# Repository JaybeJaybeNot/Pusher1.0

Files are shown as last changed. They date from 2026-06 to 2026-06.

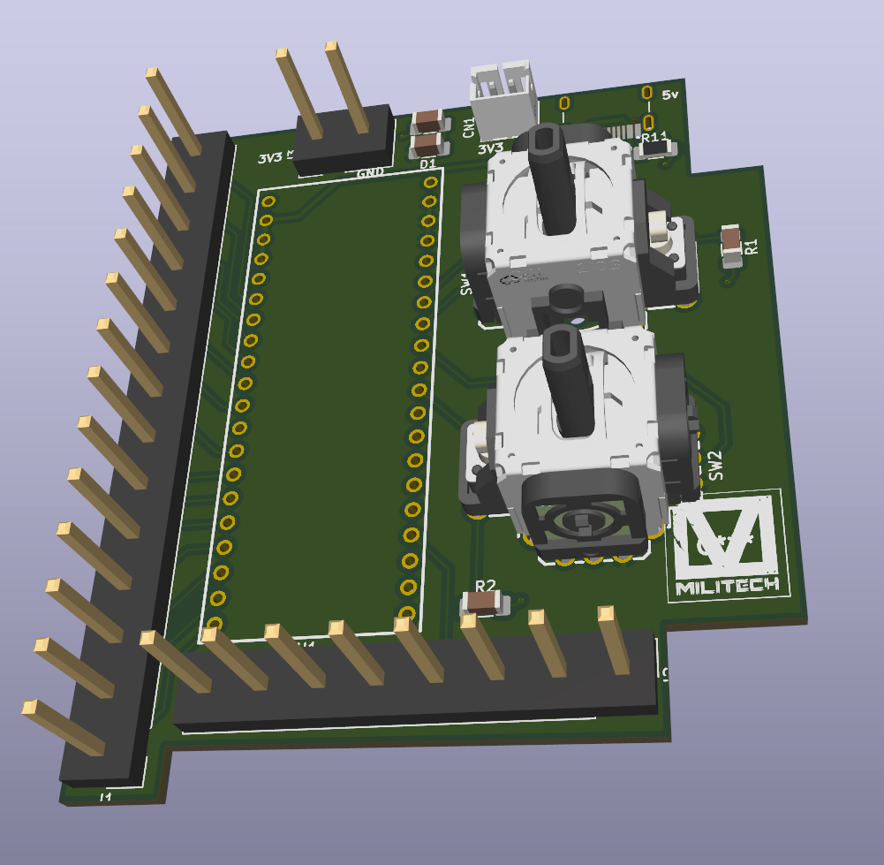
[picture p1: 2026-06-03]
Electrical Design/Joystick_Controller_Preview.png

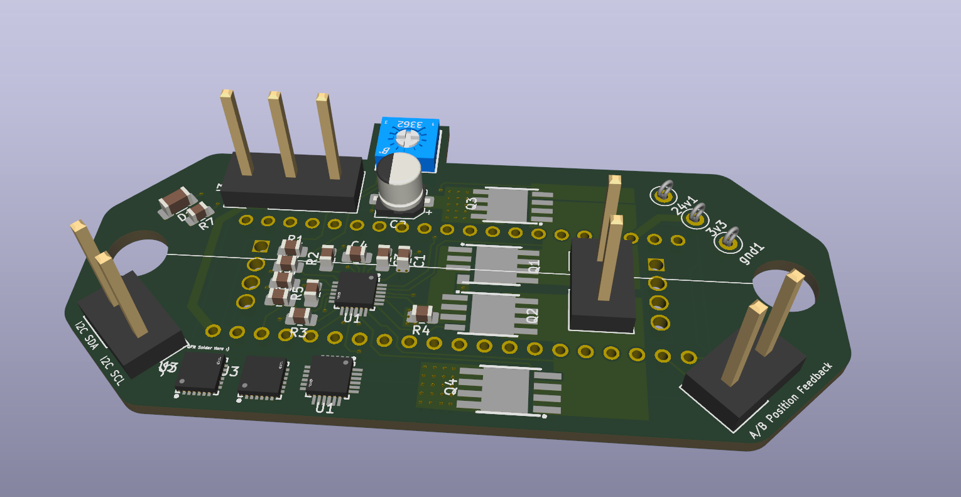
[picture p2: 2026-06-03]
Electrical Design/Motor_Driver_Preview.png

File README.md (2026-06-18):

<p align="center"><i>June 8, 2026</i></p>

Pusher-A5-2

**Affiliation:** Fallout, Hackclub

Sanity Checked by a friend, a CS Graduate from UofM working in robotics.

Pusher is a **4 Degree of Freedom wearable robotic arm** based on the anatomical structure of the human arm, with a maximum reach of approximately **0.65 meters** and a weight of **5 kilograms**. It is designed for **modularity**, aiming to serve as an affordable, general-purpose **research platform** for Human-Computer Interfacing, such as studies involving **EMG, EEG, and Computer Vision**, to assist in the **control of supernumerary arms**. As such, this project is intended for both undergraduate researchers and hobbyists looking for an introduction to the study of HCI robotics, with potential to be used in graduate-school prototyping due to the ease of production and low cost.

***Why I Started This Project***

On the surface level, the this project may seem to simply be a project aiming to develop a supernumerary, robotic arm to assist in human tasks. However, due to the modularity and inexpensiveness of the project, it serves as an amazing platform to prototype with robot theory, from inverse kinematics to computer vision, EEG/EMG signal processing, path planning, control algorithms, etc. without burning cash on hardware. In short, due to my background as an underfunded hardware researcher, I've made the "project to enable future projects"

<h1 align="center"><u>Table of Contents</u></h1>

1. [Bill of Materials](#bill-of-materials)
2. [System Diagram](#system-diagram)
3. [Building the Project](#building-the-project)
   1. [Prerequisites](#prerequisites)
   2. [Assembling Mechanical Design](#assembling-mechanical-design)
   3. [Assembling Electrical Design](#assembling-electrical-design)
   4. [Flashing Firmware](#flashing-firmware)
4. [Author's Notes](#authors-notes)
   1. [Commentary on BOM](#commentary-on-bom)
   2. [Guide to Adding Implementations (Taking Advantage of Modularity)](#guide-to-adding-implementations-taking-advantage-of-modularity)
   3. [Future Implementations by Author](#future-implementations-by-author)

<h1 align="center"><u>Bill of Materials</u></h1>

### Electronics

| Index | LCSC # | Quantity | Value | Link |
|---|---:|---:|---:|---|
| 1 | C146170 | 2 | 1.81 | [LCSC](https://www.lcsc.com/product-detail/C146170.html) |
| 2 | C22396880 | 6 | 10.34 | [LCSC](https://www.lcsc.com/product-detail/C22396880.html) |
| 3 | C49678 | 100 | 0.84 | [LCSC](https://www.lcsc.com/product-detail/C49678.html) |
| 4 | C72487 | 20 | 0.57 | [LCSC](https://www.lcsc.com/product-detail/C72487.html) |
| 5 | C24123 | 20 | 0.30 | [LCSC](https://www.lcsc.com/product-detail/C24123.html) |
| 6 | C3869051 | 20 | 0.57 | [LCSC](https://www.lcsc.com/product-detail/C3869051.html) |
| 7 | C8465 | 5 | 0.67 | [LCSC](https://www.lcsc.com/product-detail/C8465.html) |
| 8 | C72334 | 5 | 1.01 | [LCSC](https://www.lcsc.com/product-detail/C72334.html) |
| 9 | C86513 | 4 | 6.79 | [LCSC](https://www.lcsc.com/product-detail/C86513.html) |
| 10 | C114548 | 100 | 0.36 | [LCSC](https://www.lcsc.com/product-detail/C114548.html) |
| 11 | C2930231 | 100 | 0.19 | [LCSC](https://www.lcsc.com/product-detail/C2930231.html) |
| 12 | C90964 | 5 | 3.70 | [LCSC](https://www.lcsc.com/product-detail/C90964.html) |
| 13 | C58159 | 1 | 0.38 | [LCSC](https://www.lcsc.com/product-detail/C58159.html) |
| 14 | C7467397 | 50 | 0.65 | [LCSC](https://www.lcsc.com/product-detail/C7467397.html) |
| 15 | C2930266 | 100 | 0.19 | [LCSC](https://www.lcsc.com/product-detail/C2930266.html) |
| 16 | C2907315 | 100 | 0.22 | [LCSC](https://www.lcsc.com/product-detail/C2907315.html) |
|  |  | **Total** | **28.59** |  |

### Mechanical

| Part name | Quantity | Value | Link |
|---|---:|---:|---|
| PLA Filament | 1 | 7.36 | [AliExpress](https://www.aliexpress.us/item/3256806054300015.html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) |
| motors | 4 | 30 | [Precision Mini Drives](https://precisionminidrives.com/product/shaft-diameter-8mm-10mm-micro-dc-gear-motor-model-nfp-42-775-ce-12v-24v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) |
| RU-28 | 4 | 19.91 | [AliExpress](https://www.aliexpress.us/item/3256809392312866.html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) |
| M5 Screws (x50) | 1 | 15 | [Amazon Japan](https://www.amazon.co.jp/-/en/Button-Socket-Screws-Finish-BHSSM5X10B-50-SL/dp/B07DZN3FP5) |
| M3 screws and nuts (x20) | 1 | 9 | [Amazon Japan](https://www.amazon.co.jp/-/en/Phillips-Machine-Washers-Plastic-Countersunk/dp/B0B9YGNKV6) |
| m5 nuts (x50) | 1 | 13 | [Amazon Japan](https://www.amazon.co.jp/-/en/Thin-Nuts-Stainless-Steel-Flat/dp/B0CQ55XWQX?th=1) |
|  |  | **Total** | **244** |

**Total project cost:** **272.59**

<h1 align="center"><u>System Diagram</u></h1>

Screenshot 2026-06-12 at 7 11 54 PM

<h1 align="center"><u>Building the Project</u></h1>

## Prerequisites

what you will need:

- A 3d printer such as Bambu Lab capable of a printing area of 
- VS Code (my goat!)
- STM32CubeIDE 
- If you have v2.0 and later versions of STM32CubeIDE, you’ll also need STM32CubeMX
- ESP32 IDF
- Cura 
- an STM32 Nucleo Board
- Soldering:

Soldering:

- Soldering iron 
- Brass wool (sponges is useable, but not recommended) 
- Flux 
- Soldering gun 
- Fume extractor 
- Solder wick (recommended to remove excess solder) 

## Assembling Mechanical Design

Screenshot 2026-06-12 at 7 12 18 PM

For assembly, please see the `FINAL ASSEMBLY` file in the `mechanical design` folder, opened in CAD software such as Fusion 360.

The material modeled for stress testing and manufacturability is PLA plastic, intended for 3D printers such as the Bambu models.

In a slicer such as Cura, print the following:

- 1x `Bicep_And_Cap`
- 1x `Bicep_RU_28_Connector` (in `Bicep_And_Cap`)
- 1x `Forearm`
- 3x `Joint_Cover`
- 1x `Joint1`
- 2x `Joints_2_and_3`
- 3x `RU_28_Connector`

Approximately ~2 kg in PLA.

To assemble the physical design, it is recommended to have 30x M5 screws (10 mm) and 30x matching nuts. Then, use 15x M3 screws (10 mm) with 15x matching nuts.

## Assembling Electrical Design

Trusted vendors such as [JLCPCB](https://jlcpcb.com/) and [LCSC](https://www.lcsc.com/).

After ordering your PCB and components from JLCPCB and LCSC, hand-solder them as follows:

- 4x motor driver PCBs

  Screenshot 2026-06-12 at 7 13 52 PM

- 1x main controller PCB

  Screenshot 2026-06-12 at 7 14 03 PM

Motor driver PCBs are secured in a dedicated mount, 

Screenshot 2026-06-12 at 7 14 15 PM

which is fastened to the joints themselves.

Screenshot 2026-06-12 at 7 14 32 PM

Screenshot 2026-06-12 at 7 14 49 PM

The controller PCB is left separate from the rest of the arm. The recommended option is to keep it on a desk during assembly and strap it to the arm during operation.

The wiring diagram is as follows:

- Red — 24 V and 3.3 V power supply bus
- Yellow — I2C communication bus

Connections:

- From Joint 1 to Joint 2\
  
  Screenshot 2026-06-12 at 7 15 09 PM
  
- From Joint 2 to Joint 3

  Screenshot 2026-06-12 at 7 15 31 PM

- From Joint 3 to Bicep
  
Screenshot 2026-06-12 at 7 15 42 PM

The firmware includes a 360-degree clamp to prevent wires from excessive twisting and strain.

## Flashing Firmware

### Flashing STM32F103C8T6
Note: The firmware should all be in the “Brushed_DC_Motor_Controller_STM32” folder (this is the folder you select for “create project from existing stm32cubeide project”). But for additional documentation, the pinouts and clock configuration is provided below:

In STM32cubeMX, configure the pins as follows:

Screenshot 2026-06-12 at 7 16 09 PM

Now, in the Clock tab, configure the clocks as follows:

Screenshot 2026-06-12 at 7 17 12 PM

Note: The firmware should be placed in the `Brushed_DC_Motor_Controller_STM32` folder. This is the folder you select when creating a project from an existing STM32CubeIDE project.

Step 1: Connect the SWDIO, SWCLK, GND, and 3v3 on the Motor Driver stm32 with the corresponding pins on your ST-LINK. Preferably, any STM32Nucleo can be used in order to avoid third party flashers that do not work. (trust me, speaking from experience). 

Screenshot 2026-06-12 at 7 17 55 PM

(Remove the “ST-Link isolation jumpers” on CN2 on the Nucleo Board so that you’re programming the dc motor driver, not the Nucleo itself)

Step 2: Import “Brushed_DC_Motor_Controller_STM32” as an “Existing STM32 project” into stm32cubeIDE. 

Step 3: Open the project, and find the build tool on the top toolbar, then click on it: 

Screenshot 2026-06-12 at 7 18 11 PM

Verify that there are no errors. Most build errors arise from workspace configuration. If that happens, close STM32CubeIDE first. Then, reopen. When it asks for a workspace, select the “Software” folder. It should create the corresponding metadata files. Confirm that files are there. 

Step 4: Click on “debug” tool. 

Screenshot 2026-06-12 at 7 18 20 PM

Step 5: Click on “Run”:

Screenshot 2026-06-12 at 7 18 29 PM

If flashing succeeds, STM32CubeIDE should display a successful download message in the console.

### Flashing ESP32

1. Follow the steps in the AKP's IoT Tech video to download and set up ESP32 IDF. Stop around 4:20, after creating a project folder.

YouTube video: https://www.youtube.com/watch?v=xQ-Zk0FaK-c

2. At 4:20, replace the code in `hello_world_main.c` with the contents of `main.c` located in the `ESP32 Joystick Controller` folder.
3. The code does not use external libraries, so no additional imports are needed.
4. In the ESP32-IDF terminal, type:

```bash
idf.py set-target esp32
idf.py build
```

5. Connect the ESP32 to your computer via USB.

On Windows, select the ESP32 model and the communication port. Ports usually appear as `COMx`.

Then run:

```bash
idf.py -p COM3 flash
```

Replace `3` in `COM3` with the corresponding COM number.

#### Mac

On Mac, ports usually appear as `/dev/ttyUSBx`.

You can identify the port with:

```bash
ls -la /dev | grep -E "cu\.(SLAB|usbserial)"
```

Then follow these steps:

```bash
source ~/esp/esp-idf/export.sh
idf.py set-target esp32
idf.py -p /dev/cu.SLAB_USBtoUART flash
```

#### Linux

On Linux, ports usually appear as `/dev/ttyACMx`.

First, add your user to the hardware access group:

Ubuntu/Debian:

```bash
sudo usermod -aG dialout $USER
```

Arch Linux:

```bash
sudo usermod -aG uucp $USER
```

Then, find the device path with:

```bash
ls /dev/ttyUSB* /dev/ttyACM*
```

Then navigate into your project directory and select the model:

```bash
idf.py set-target esp32
```

Finally, flash and monitor:

```bash
idf.py -p /dev/ttyUSB0 flash monitor
```

Replace `/dev/ttyUSB0` with the actual device path identified above.

<h1 align="center"><u>Author's Notes</u></h1>

## Commentary on BOM

## Guide to Adding Implementations (Taking Advantage of Modularity)

## Future Implementations by Author

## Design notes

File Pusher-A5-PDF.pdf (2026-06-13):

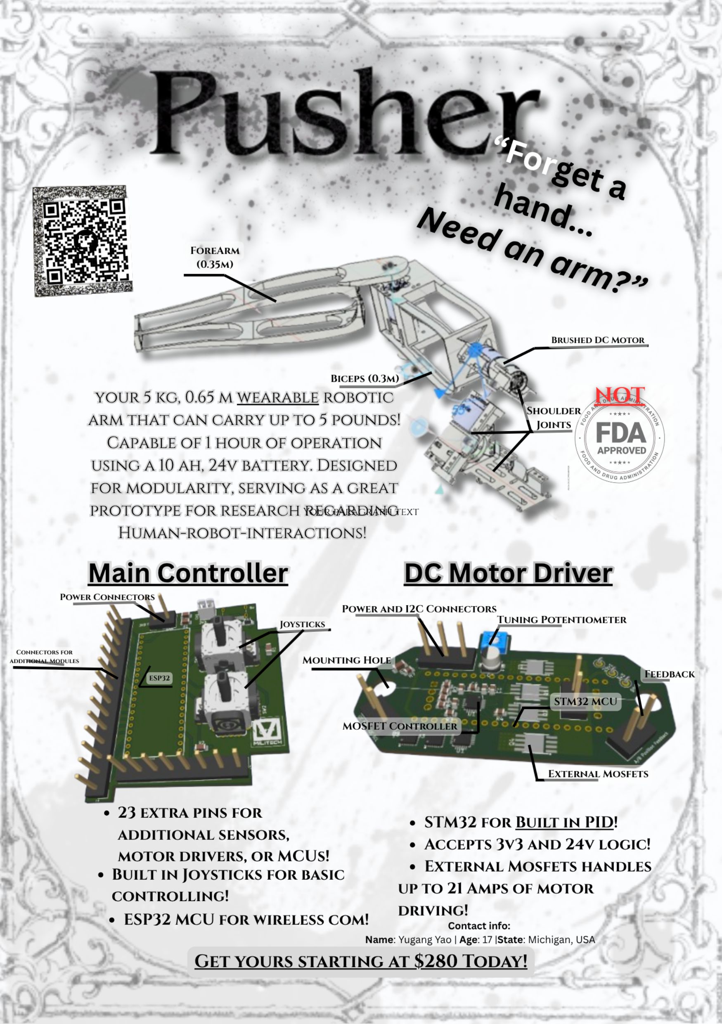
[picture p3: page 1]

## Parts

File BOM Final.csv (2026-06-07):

Part name |  | Quantity | Value | LCSC # / Link
Electronics
Index | LCSC# | MPN | Manufacturer | Package | Customer # | Description | RoHS | Quantity | MOQ | Multiple | Unit Price($) | Extended Price($) | Product Link
1 | C146170 | RKJXV1224005 | ALPSALPINE | Through Hole,13x13mm |  | Through Hole,13x13mm Navigation Switches, Joystick RoHS | yes | 2 | 1 | 1 | 0.9044 | 1.81 | https://www.lcsc.com/product-detail/C146170.html
2 | C22396880 | LCKFB-DKX-STM32F103C8T6 | LCSC-boards | - |  | Embedded MCU, DSP Evaluation Boards RoHS | yes | 6 | 1 | 1 | 1.7239 | 10.34 | https://www.lcsc.com/product-detail/C22396880.html
3 | C49678 | CC0805KRX7R9BB104 | YAGEO | 805 |  | 100nF ±10% 50V Ceramic Capacitor X7R 0805 | yes | 100 | 100 | 100 | 0.0084 | 0.84 | https://www.lcsc.com/product-detail/C49678.html
4 | C72487 | RVT1H100M0505 | ROQANG | SMD,D5xL5.4mm |  | 10uF ±20% 50V Aluminum Electrolytic Capacitors 2000hrs@105℃ | yes | 20 | 20 | 20 | 0.0284 | 0.57 | https://www.lcsc.com/product-detail/C72487.html
5 | C24123 | CL21B105KOFNNNE | Samsung Electro-Mechanics | 805 |  | 1uF ±10% 16V Ceramic Capacitor X7R 0805 | yes | 20 | 20 | 20 | 0.015 | 0.3 | https://www.lcsc.com/product-detail/C24123.html
6 | C3869051 | AC0805KKX7R5BB105 | YAGEO | 805 |  | 1uF ±10% 6.3V Ceramic Capacitor X7R 0805 | yes | 20 | 20 | 20 | 0.0285 | 0.57 | https://www.lcsc.com/product-detail/C3869051.html
7 | C8465 | WJ500V-5.08-2P | KANGNEX | Through Hole,P=5.08mm |  | 2 Position Wire to Board Terminal Block Through Hole 5.08mm | yes | 5 | 5 | 5 | 0.1336 | 0.67 | https://www.lcsc.com/product-detail/C8465.html
8 | C72334 | WJ500V-5.08-03P-14-00A | KANGNEX | Through Hole,P=5.08mm |  | 3 Position Wire to Board Terminal Block Through Hole 5.08mm | yes | 5 | 5 | 5 | 0.202 | 1.01 | https://www.lcsc.com/product-detail/C72334.html
9 | C86513 | CSD18540Q5B | TI | VSON-8(5x6) |  | N-Channel 60V 205A 3.8W Surface Mount VSON-8(5x6) | yes | 4 | 1 | 1 | 1.6973 | 6.79 | https://www.lcsc.com/product-detail/C86513.html
10 | C114548 | RC0805FR-0768KL | YAGEO | 805 |  | 68kΩ 125mW 150V Thick Film Resistor ±100ppm/℃ ±1% 0805 Chip Resistor - Surface Mount RoHS | yes | 100 | 100 | 100 | 0.0036 | 0.36 | https://www.lcsc.com/product-detail/C114548.html
11 | C2930231 | FRC0805J103TS | FOJAN | 805 |  | 10kΩ ±5% 125mW 0805 Thick Film Resistor | yes | 100 | 100 | 100 | 0.0019 | 0.19 | https://www.lcsc.com/product-detail/C2930231.html
12 | C90964 | DRV8701ERGER | TI | VQFN-24-EP(4x4) |  | Full-Bridge MOSFET 150mA 300mA VQFN-24-EP(4x4) Motor Drivers, Controllers RoHS | yes | 5 | 1 | 1 | 0.7397 | 3.7 | https://www.lcsc.com/product-detail/C90964.html
13 | C58159 | 3362P-1-103LF | BOURNS | Through Hole-3P,7x6.6mm |  | 10kΩ ±10% 500mW Through Hole-3P,7x6.6mm Potentiometers, Variable Resistors | yes | 1 | 1 | 1 | 0.3763 | 0.38 | https://www.lcsc.com/product-detail/C58159.html
14 | C7467397 | FRL0805FR030TS | FOJAN | 805 |  | 30mΩ 125mW Thick Film Resistor ±1200ppm/℃ ±1% 0805 Chip Resistor - Surface Mount RoHS | yes | 50 | 50 | 50 | 0.013 | 0.65 | https://www.lcsc.com/product-detail/C7467397.html
15 | C2930266 | FRC0805J332TS | FOJAN | 805 |  | 3.3kΩ ±5% 125mW 0805 Thick Film Resistor | yes | 100 | 100 | 100 | 0.0019 | 0.19 | https://www.lcsc.com/product-detail/C2930266.html
16 | C2907315 | FRC0805J202 TS | FOJAN | 805 |  | 2kΩ ±5% 125mW 0805 Thick Film Resistor | yes | 100 | 100 | 100 | 0.0022 | 0.22 | https://www.lcsc.com/product-detail/C2907315.html
 |  |  |  |  |  |  |  |  |  |  | total: | 28.59
Mechanical |  |  | price (USD) | link
PLA Filament |  | 1 | 7.36 | https://www.aliexpress.us/item/3256806054300015.html?curPageLogUid=Qx4M7j8exyPx
motors |  | 4 | 30 | https://precisionminidrives.com/product/shaft-diameter-8mm-10mm-micro-dc-gear-motor-model-nfp-42-775-ce-12v-24v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
RU-28 |  | 4 | 19.91 | https://www.aliexpress.us/item/3256809392312866.html?src=google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
M5 Screws (x50) |  | 1 | 15 | https://www.amazon.co.jp/-/en/Button-Socket-Screws-Finish-BHSSM5X10B-50-SL/dp/B07DZN3FP5
M3 screws and nuts (x20) |  | 1 | 9 | https://www.amazon.co.jp/-/en/Phillips-Machine-Washers-Plastic-Countersunk/dp/B0B9YGNKV6
m5 nuts (x50) |  | 1 | 13 | https://www.amazon.co.jp/-/en/Thin-Nuts-Stainless-Steel-Flat/dp/B0CQ55XWQX?th=1
 |  | Total: | 244

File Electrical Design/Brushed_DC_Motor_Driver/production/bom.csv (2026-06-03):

Designator | Footprint | Quantity | Value | LCSC Part #
24V1, 3V3, GND1 | TestPoint_Loop_D2.50mm_Drill1.0mm_LowProfile | 3 | TestPoint
C1, C4 | 0805 | 2 | 0.1 uF
C2 | CP_Elec_5x5.4 | 1 | 10 uF
C3 | 0805 | 1 | 1 uF, 16V
C5, C6 | 0805 | 2 | 1 uF, 6.3v
D1 | 1206 | 1 | LED
J1 | Samtec_HPM-02-01-x-S_Straight_1x02_Pitch5.08mm | 1 | Conn_01x02_Pin
J3 | Samtec_HPM-03-01-x-S_Straight_1x03_Pitch5.08mm | 1 | Conn_01x03_Pin
J4 | Samtec_HPM-02-01-x-S_Straight_1x02_Pitch5.08mm | 1 | A/B Position Feedback
J5 | Samtec_HPM-02-01-x-S_Straight_1x02_Pitch5.08mm | 1 | PWM
Q1, Q2, Q3, Q4 | VSON-CLIP-8_L5.0-W6.0-P1.27-BL | 4 | ~
R1 | 0805 | 1 | 2k R
R2 | 0805 | 1 | 3.3kR
R3 | 0805 | 1 | 68k R
R4 | 0805 | 1 | 0.03 R
R5, R6, R7 | 0805 | 3 | 10k R
U1_2, U1, U3_2, U3 | VQFN-24_L4.0-W4.0-P0.50-BL-EP2.5 | 4 | ~
U2 | CONN-TH_L53.3-W22.9_STM32F103C8T6-CARD | 1 | ~
VR1 | RES-ADJ-TH_3362P | 1 | 10kΩ

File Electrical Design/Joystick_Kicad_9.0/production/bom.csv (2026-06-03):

Designator | Footprint | Quantity | Value | LCSC Part #
CN1 | CONN-TH_B2B-PH-K-S | 1 | ~
D1 | 1206 | 1 | LED
J1 | Samtec_HPM-14-01-x-S_Straight_1x14_Pitch5.08mm | 1 | Conn_01x14_Pin
J2 | Samtec_HPM-08-01-x-S_Straight_1x08_Pitch5.08mm | 1 | Conn_01x08_Pin
J3 | Samtec_HPM-02-01-x-S_Straight_1x02_Pitch5.08mm | 1 | Conn_01x02_Pin
J4 | SHOUHAN_TYPE-C_16PIN_2MD__073_ | 1 | TYPE-C_16PIN_2MD__073_
R1, R2 | 1206 | 2 | R
R10, R11 | 1206 | 2 | 5.1k R
R3 | 1206 | 1 | <1k
SW1, SW2 | SW-TH_RKJXV1224005 | 2 | ~
U1 | DIP-40_L20.32-W51.66-P2.54-LS15.24 | 1 | ~

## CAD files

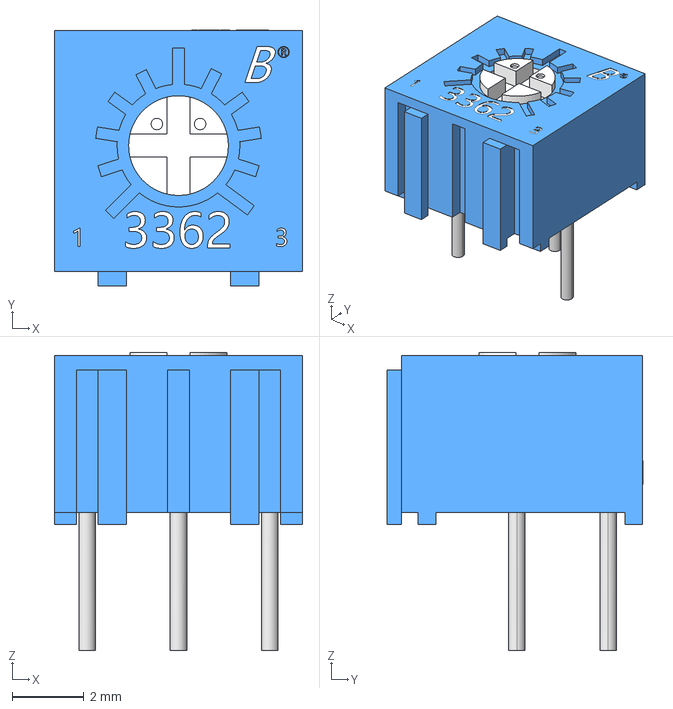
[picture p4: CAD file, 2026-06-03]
Electrical Design/Brushed_DC_Motor_Driver/EASYEDA_MODELS/3362P.step
6.90 x 7.10 x 8.28 mm

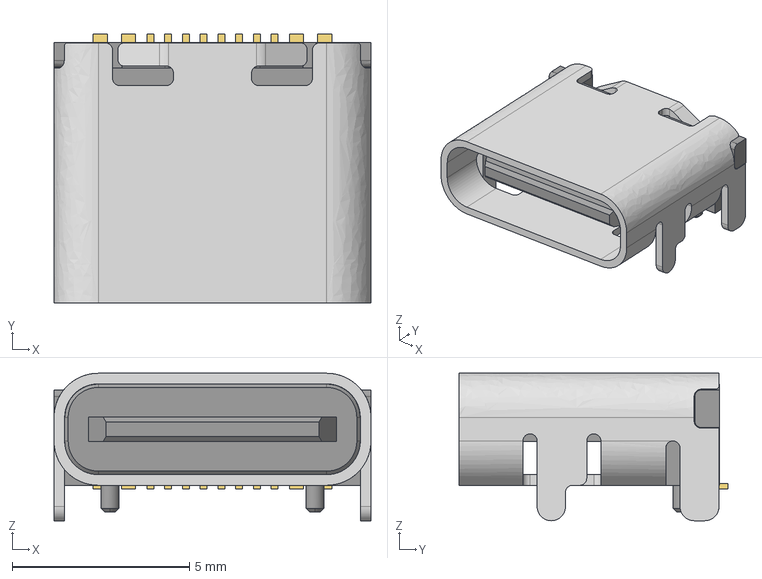
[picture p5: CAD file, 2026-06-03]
Electrical Design/Joystick_Kicad_9.0/EASYEDA_MODELS/USB-C-SMD_TYPE-C-6PIN-2MD-073.step
8.94 x 7.58 x 4.16 mm

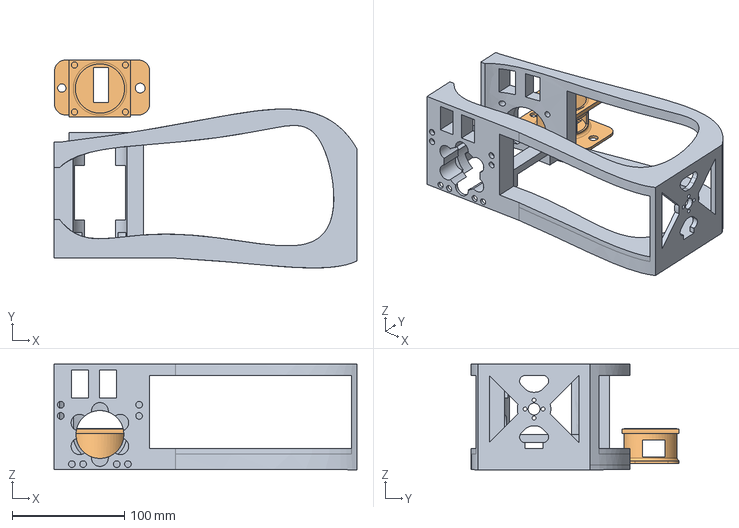
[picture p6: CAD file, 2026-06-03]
Mechanical Design/Bicep_And_Cap/Bicep_and_cap.step
270.4 x 185.6 x 94.2 mm

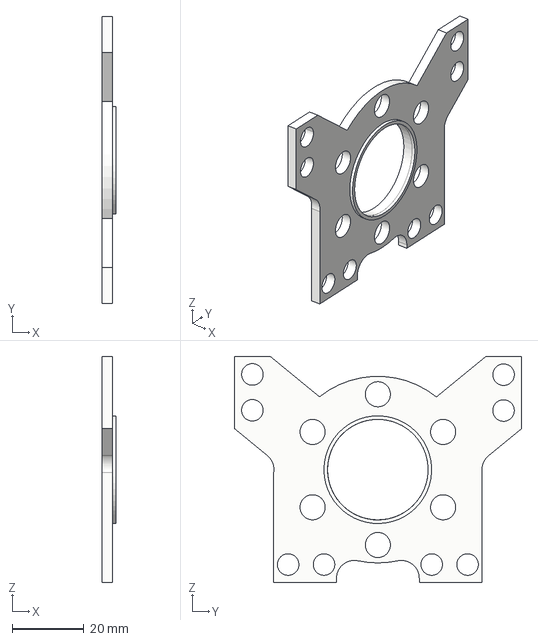
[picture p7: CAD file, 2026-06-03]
Mechanical Design/Bicep_And_Cap/Bicep_RU_28_Connector/Bicep_RU_28_Cover.step
4.00 x 80.1 x 63.0 mm

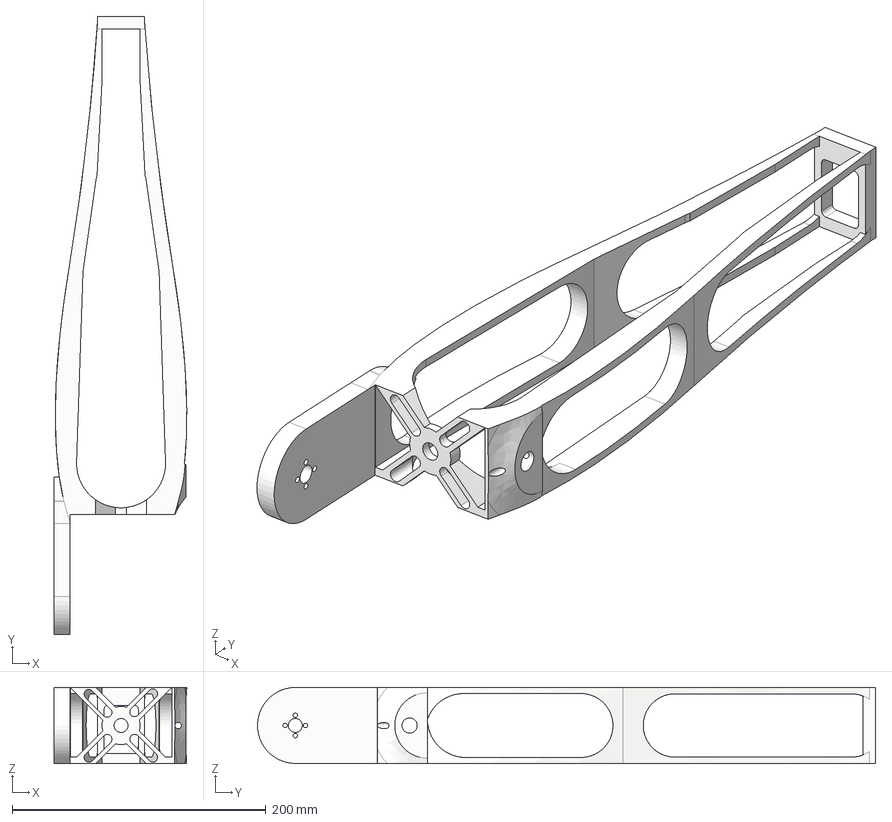
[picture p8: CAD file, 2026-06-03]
Mechanical Design/Forearm/Forearm.step
104.4 x 486.9 x 60.0 mm

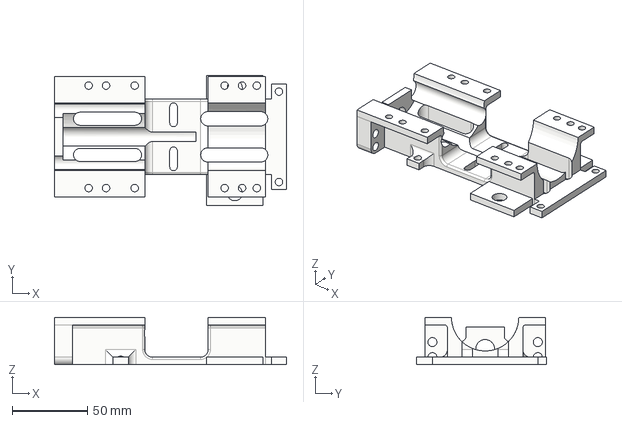
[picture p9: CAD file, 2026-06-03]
Mechanical Design/Joint1/Joint_1.step
154.0 x 86.1 x 31.5 mm

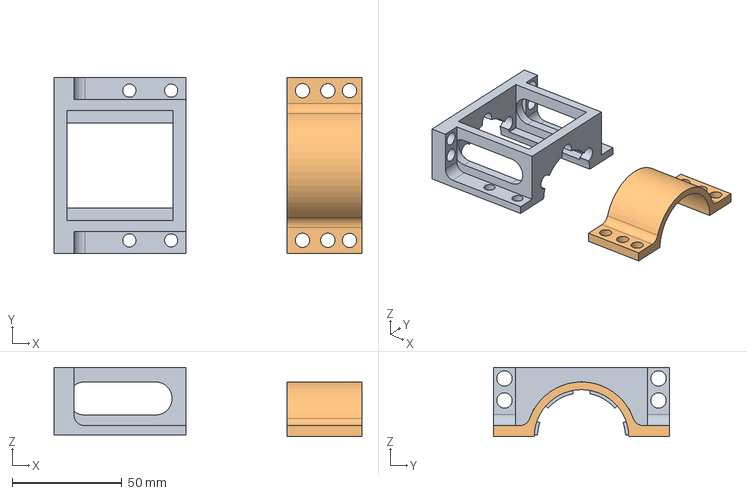
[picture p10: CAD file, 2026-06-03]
Mechanical Design/Joint_Cover/Joint_Cover.step
140.0 x 80.0 x 31.5 mm

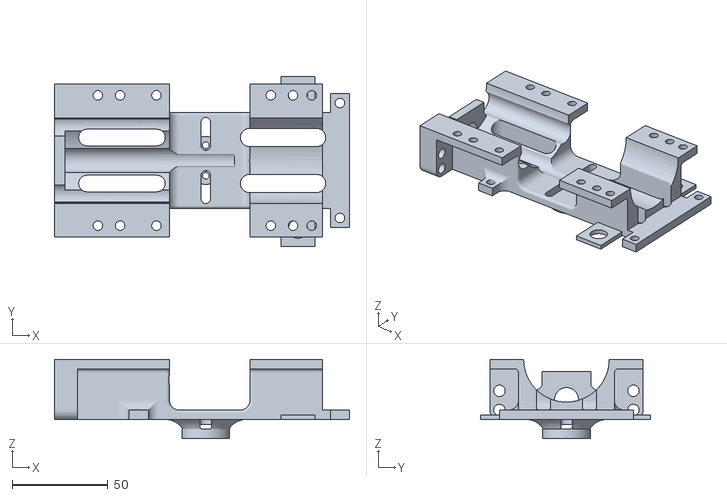
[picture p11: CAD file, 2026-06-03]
Mechanical Design/Joints_2_and_3/Joints_2_and_3.stl
154.0 x 88.9 x 41.5

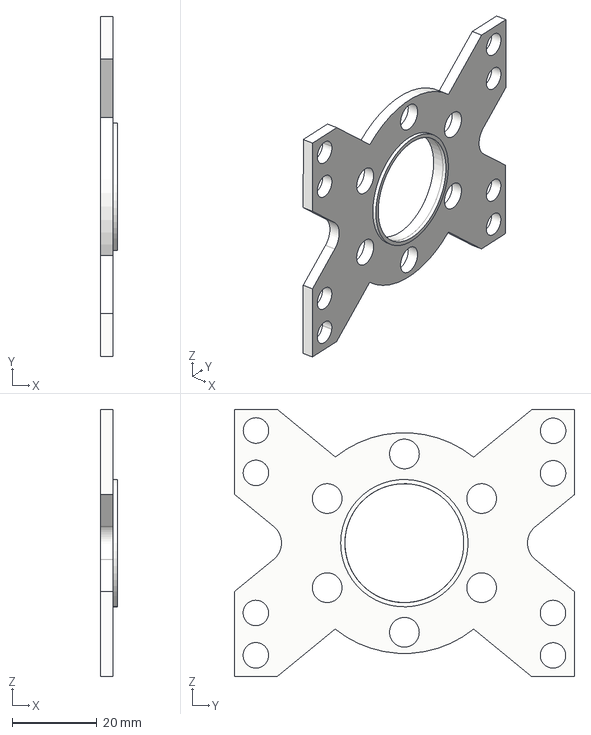
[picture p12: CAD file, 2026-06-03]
Mechanical Design/RU_28_Connector/RU_28_Connector.step
4.00 x 80.1 x 63.0 mm

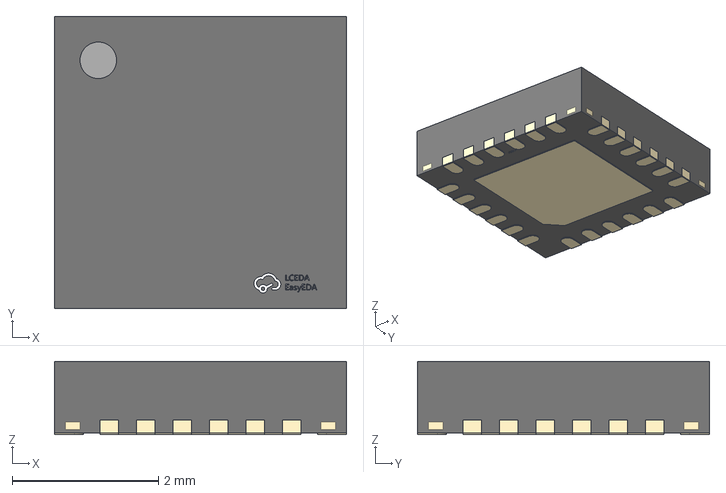
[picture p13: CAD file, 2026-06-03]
Electrical Design/Brushed_DC_Motor_Driver/EASYEDA_MODELS/VQFN-24_L4.0-W4.0-H1.0-P0.50-BL-EP2.5.step
4.00 x 4.00 x 1.00 mm

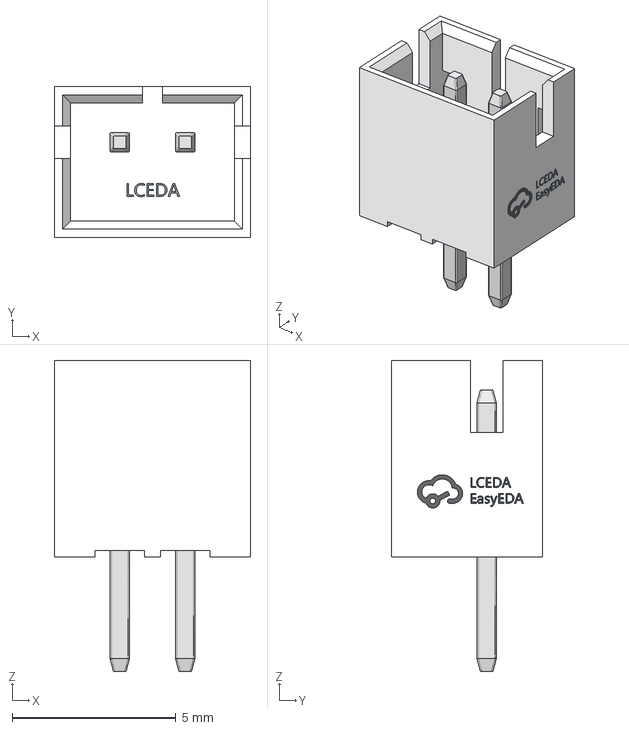
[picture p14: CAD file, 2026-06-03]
Electrical Design/Joystick_Kicad_9.0/EASYEDA_MODELS/CONN-TH_PH2.00-LI-2P.step
6.00 x 4.60 x 9.50 mm

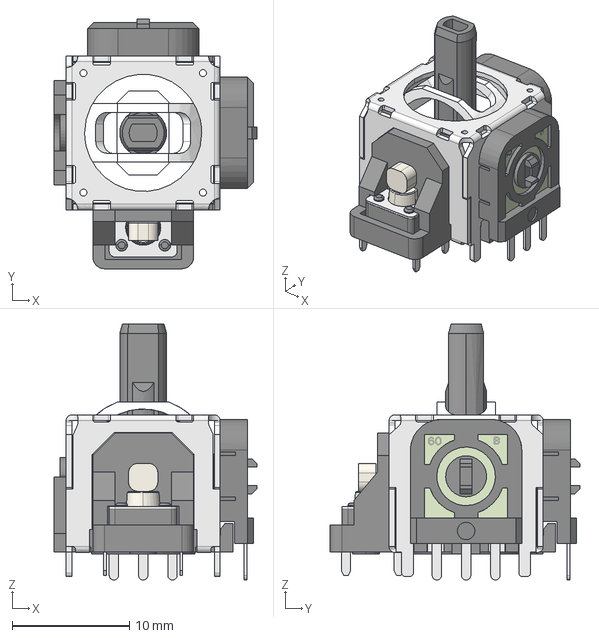
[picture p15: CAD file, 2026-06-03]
Electrical Design/Joystick_Kicad_9.0/EASYEDA_MODELS/SW-TH_RKJXV1224005.step
17.3 x 21.3 x 21.8 mm

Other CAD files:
Mechanical Design/Joints_2_and_3/SecondAndThirdJoint.step
Mechanical Design/Bicep_And_Cap/Bicep_RU_28_Connector/Bicep_RU_28_Cover.f3d
Mechanical Design/Bicep_And_Cap/Bicep_RU_28_Connector/Bicep_RU_28_Cover.stl
Mechanical Design/Bicep_And_Cap/Bicep_and_cap.stl
Mechanical Design/Forearm/Forearm.stl
Mechanical Design/Joint1/Joint_1.stl
Mechanical Design/Joint_Cover/Joint_Cover.f3z
Mechanical Design/Joint_Cover/Joint_Cover.stl
Mechanical Design/RU_28_Connector/RU_28_Connector.stl
Mechanical Design/RU_28_Connector/Ru28_Connector.f3d

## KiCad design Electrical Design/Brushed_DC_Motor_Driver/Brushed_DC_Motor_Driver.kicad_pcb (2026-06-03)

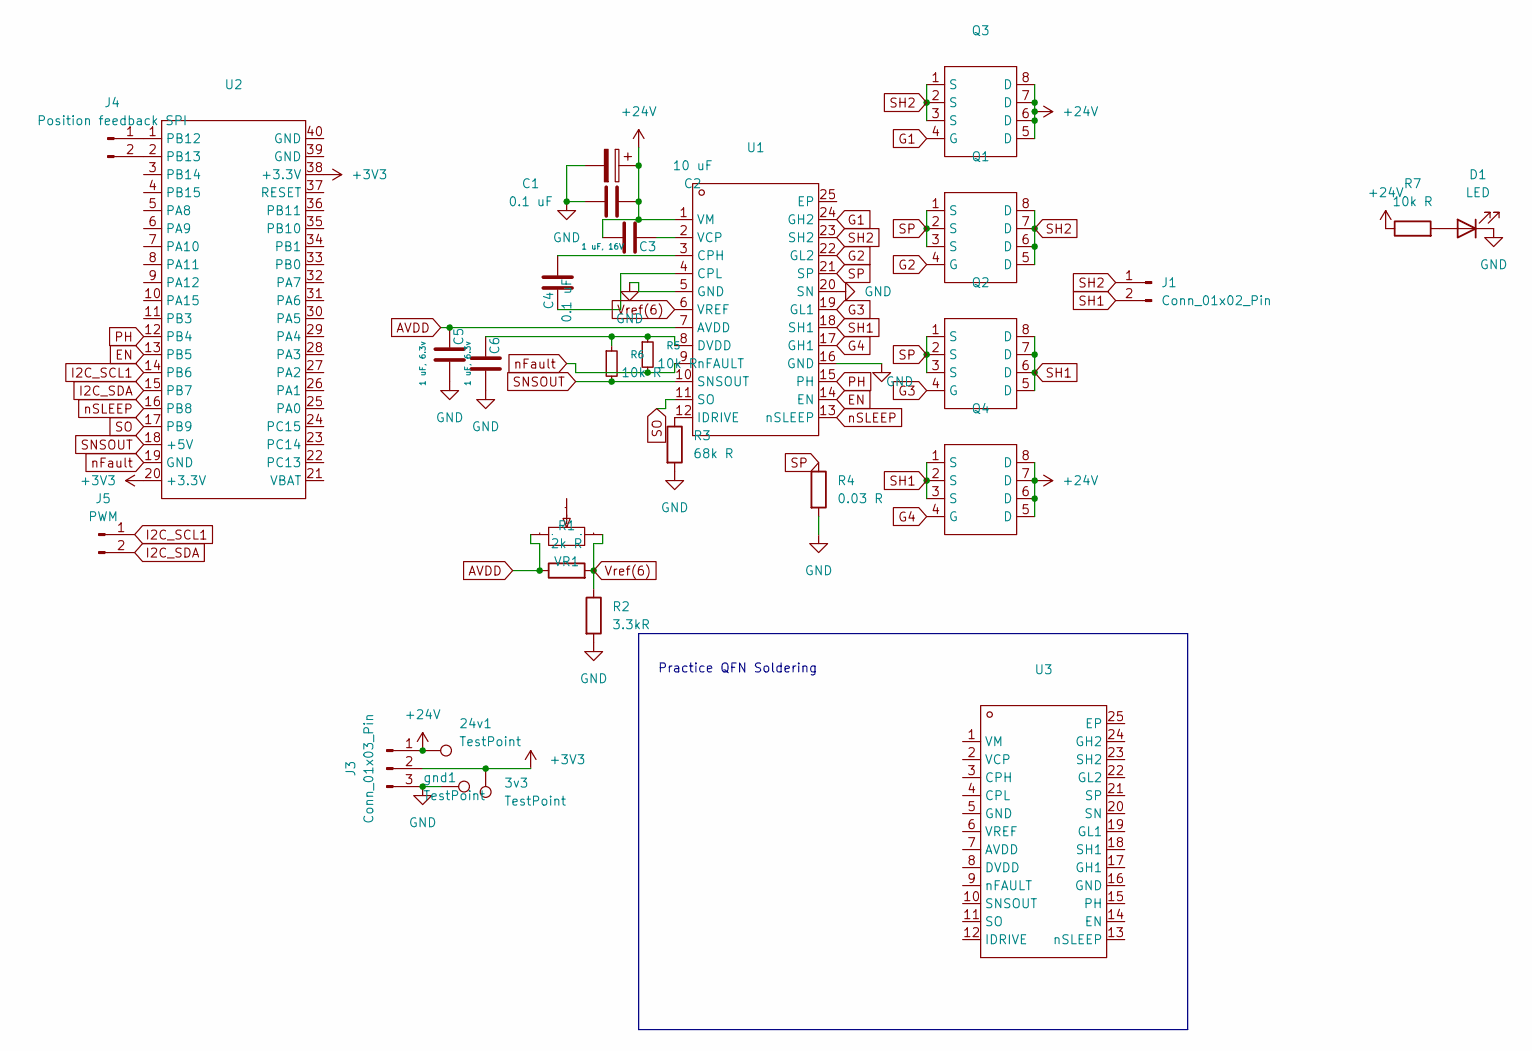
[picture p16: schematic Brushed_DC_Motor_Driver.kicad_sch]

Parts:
3v3, 24v1: TestPoint; TestPoint_Loop_D2.50mm_Drill1.0mm_LowProfile
C1, C4: 0.1 uF; C_0805_2012Metric_Pad1.18x1.45mm_HandSolder
C2: 10 uF; CP_Elec_5x5.4
C3: 1 uF, 16V; C_0805_2012Metric_Pad1.18x1.45mm_HandSolder
C5, C6: 1 uF, 6.3v; C_0805_2012Metric_Pad1.18x1.45mm_HandSolder
D1: LED; C_1206_3216Metric_Pad1.33x1.80mm_HandSolder
J1: Conn_01x02_Pin; Samtec_HPM-02-01-x-S_Straight_1x02_Pitch5.08mm
J3: Conn_01x03_Pin; Samtec_HPM-03-01-x-S_Straight_1x03_Pitch5.08mm
J4: Position feedback SPI; Samtec_HPM-02-01-x-S_Straight_1x02_Pitch5.08mm
J5: PWM; Samtec_HPM-02-01-x-S_Straight_1x02_Pitch5.08mm
Q1, Q2, Q3, Q4: VSON-CLIP-8_L5.0-W6.0-P1.27-BL; Manufacturer Part CSD18540Q5B; LCSC Part Name 1个N沟道 耐压:60V
R1: 2k R; C_0805_2012Metric_Pad1.18x1.45mm_HandSolder
R2: 3.3kR; C_0805_2012Metric_Pad1.18x1.45mm_HandSolder
R3: 68k R; C_0805_2012Metric_Pad1.18x1.45mm_HandSolder
R4: 0.03 R; C_0805_2012Metric_Pad1.18x1.45mm_HandSolder
R5, R6, R7: 10k R; C_0805_2012Metric_Pad1.18x1.45mm_HandSolder
U1, U3: VQFN-24_L4.0-W4.0-P0.50-BL-EP2.5; Manufacturer Part DRV8701ERGER; LCSC Part Name 有刷直流电机驱动芯片 45V
U2: CONN-TH_L53.3-W22.9_STM32F103C8T6-CARD; Manufacturer Part LCKFB-DKX-STM32F103C8T6; LCSC Part Name 立创·地阔星-STM32F103C8T6开发板
VR1: 10kΩ; RES-ADJ-TH_3362P; Manufacturer Part 3362P-1-103LF; LCSC Part Name 10kΩ ±10%
gnd1: TestPoint; TestPoint_Loop_D2.50mm_Drill1.0mm_LowProfile

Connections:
+3V3: 3v3.1, J3.2, U2.20 (+3.3V), U2.38 (+3.3V)
+24V: 24v1.1, C1.2, C2.1, C3.1, J3.1, Q3.5 (D), Q3.6 (D), Q3.7 (D), Q3.8 (D), Q4.5 (D), Q4.6 (D), Q4.7 (D), Q4.8 (D), R7.1, U1.1 (VM); also elsewhere on the board
AVDD: C5.2, R1.1, U1.7 (AVDD), VR1.3; also elsewhere on the board
EN: U1.14 (EN), U2.13 (PB5); also elsewhere on the board
G1: Q3.4 (G), U1.24 (GH2); also elsewhere on the board
G2: Q1.4 (G), U1.22 (GL2); also elsewhere on the board
G3: Q2.4 (G), U1.19 (GL1); also elsewhere on the board
G4: Q4.4 (G), U1.17 (GH1); also elsewhere on the board
GND: C1.1, C2.2, C5.1, C6.1, D1.1 (K), J3.3, R2.2, R3.2, R4.2, U1.5 (GND), U1.16 (GND), U1.20 (SN), gnd1.1; also elsewhere on the board
I2C_SCL1: J5.1, U2.14 (PB6)
I2C_SDA: J5.2, U2.15 (PB7)
unnamed: D1.2 (A), R7.2
unnamed: J4.1, U2.1 (PB12)
unnamed: J4.2, U2.2 (PB13)
unnamed 14: C4.2, U1.3 (CPH); also elsewhere on the board
unnamed 15: C4.1, U1.4 (CPL); also elsewhere on the board
unnamed 16: C6.2, R5.1, R6.1, U1.8 (DVDD); also elsewhere on the board
unnamed 17: R3.1, U1.12 (IDRIVE); also elsewhere on the board
unnamed 18: C3.2, U1.2 (VCP); also elsewhere on the board
PH: U1.15 (PH), U2.12 (PB4); also elsewhere on the board
SH1: J1.2, Q2.5 (D), Q2.6 (D), Q2.7 (D), Q2.8 (D), Q4.1 (S), Q4.2 (S), Q4.3 (S), U1.18 (SH1); also elsewhere on the board
SH2: J1.1, Q1.5 (D), Q1.6 (D), Q1.7 (D), Q1.8 (D), Q3.1 (S), Q3.2 (S), Q3.3 (S), U1.23 (SH2); also elsewhere on the board
SNSOUT: R6.2, U1.10 (SNSOUT), U2.18 (+5V); also elsewhere on the board
SO: U1.11 (SO), U2.17 (PB9); also elsewhere on the board
SP: Q1.1 (S), Q1.2 (S), Q1.3 (S), Q2.1 (S), Q2.2 (S), Q2.3 (S), R4.1, U1.21 (SP); also elsewhere on the board
Vref(6): R1.2, R2.1, U1.6 (VREF), VR1.1; also elsewhere on the board
nFault: R5.2, U1.9 (nFAULT), U2.19 (GND); also elsewhere on the board
nSLEEP: U1.13 (nSLEEP), U2.16 (PB8); also elsewhere on the board

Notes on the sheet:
Practice QFN Soldering

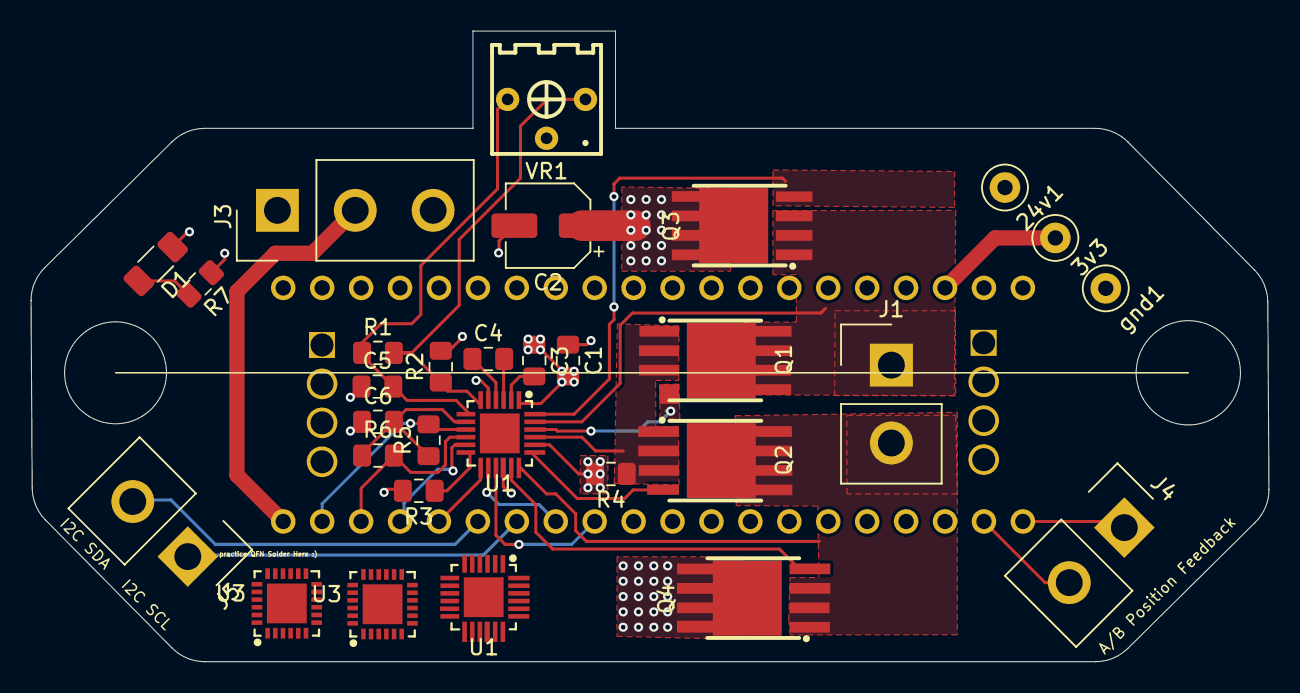
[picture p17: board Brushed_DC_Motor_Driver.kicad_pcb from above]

Board: 4 copper layers, 80.8 x 41.2 mm, 31 parts (1 on the bottom side), 28 nets.

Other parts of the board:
U1#2, U3#2: VQFN-24_L4.0-W4.0-P0.50-BL-EP2.5

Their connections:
+24V: U1#2.1 (VM); also elsewhere on the board
AVDD: U1#2.7 (AVDD); also elsewhere on the board
EN: U1#2.14 (EN); also elsewhere on the board
G1: U1#2.24 (GH2); also elsewhere on the board
G2: U1#2.22 (GL2); also elsewhere on the board
G3: U1#2.19 (GL1); also elsewhere on the board
G4: U1#2.17 (GH1); also elsewhere on the board
GND: U1#2.5 (GND), U1#2.16 (GND), U1#2.20 (SN); also elsewhere on the board
unnamed 14: U1#2.3 (CPH); also elsewhere on the board
unnamed 15: U1#2.4 (CPL); also elsewhere on the board
unnamed 16: U1#2.8 (DVDD); also elsewhere on the board
unnamed 17: U1#2.12 (IDRIVE); also elsewhere on the board
unnamed 18: U1#2.2 (VCP); also elsewhere on the board
PH: U1#2.15 (PH); also elsewhere on the board
SH1: U1#2.18 (SH1); also elsewhere on the board
SH2: U1#2.23 (SH2); also elsewhere on the board
SNSOUT: U1#2.10 (SNSOUT); also elsewhere on the board
SO: U1#2.11 (SO); also elsewhere on the board
SP: U1#2.21 (SP); also elsewhere on the board
Vref(6): U1#2.6 (VREF); also elsewhere on the board
nFault: U1#2.9 (nFAULT); also elsewhere on the board
nSLEEP: U1#2.13 (nSLEEP); also elsewhere on the board

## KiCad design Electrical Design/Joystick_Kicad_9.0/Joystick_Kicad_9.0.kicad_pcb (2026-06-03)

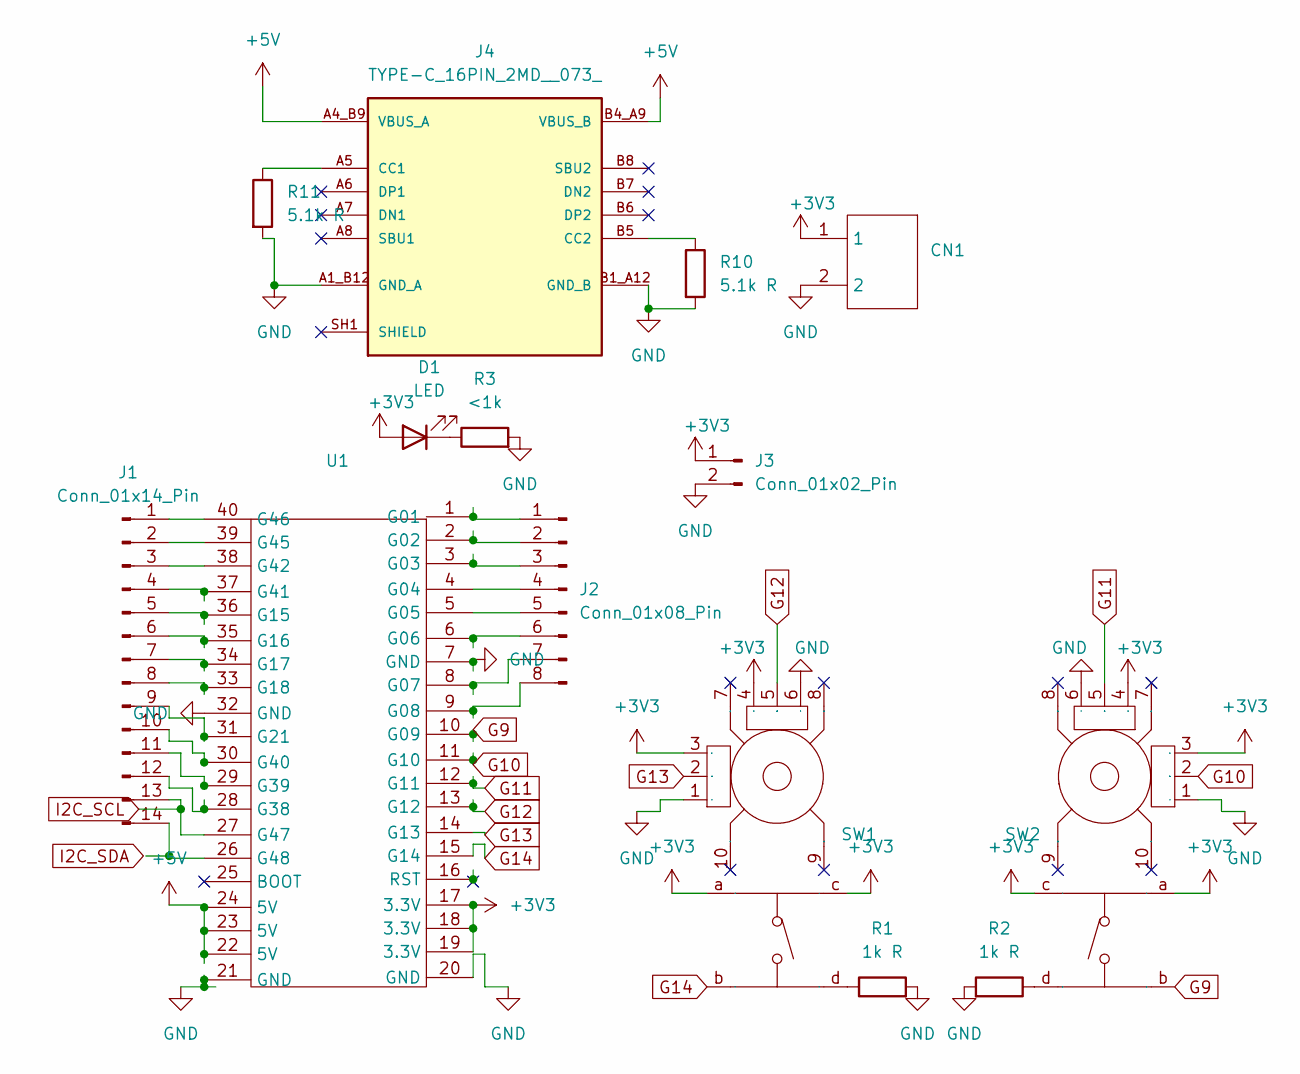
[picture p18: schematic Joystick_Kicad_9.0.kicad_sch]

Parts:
CN1: CONN-TH_B2B-PH-K-S; Manufacturer Part B2B-PH-K-S(LF)(SN); LCSC Part Name 1x2P 间距:2mm 直插 系列:PH
D1: LED; C_1206_3216Metric_Pad1.33x1.80mm_HandSolder
J1: Conn_01x14_Pin; Samtec_HPM-14-01-x-S_Straight_1x14_Pitch5.08mm
J2: Conn_01x08_Pin; Samtec_HPM-08-01-x-S_Straight_1x08_Pitch5.08mm
J3: Conn_01x02_Pin; Samtec_HPM-02-01-x-S_Straight_1x02_Pitch5.08mm
J4: TYPE-C_16PIN_2MD__073_; SHOUHAN_TYPE-C_16PIN_2MD__073_; PARTREV A
R1, R2: 1k R; C_1206_3216Metric_Pad1.33x1.80mm_HandSolder
R3: <1k; C_1206_3216Metric_Pad1.33x1.80mm_HandSolder
R10, R11: 5.1k R; R_1206_3216Metric_Pad1.30x1.75mm_HandSolder
SW1, SW2: SW-TH_RKJXV1224005; Manufacturer Part RKJXV1224005; LCSC Part Name RKJXV1224005
U1: DIP-40_L20.32-W51.66-P2.54-LS15.24; Manufacturer Part LCKFB-ESP32S3R8N8; LCSC Part Name 立创·ESP32S3R8N8 开发板

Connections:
+3V3: CN1.1, D1.2 (A), J3.1, SW1.3 (A), SW1.4 (A), SW1.a, SW1.c, SW2.3 (A), SW2.4 (A), SW2.a, SW2.c, U1.17 (3.3V), U1.18 (3.3V), U1.19 (3.3V)
+5V: J4.A4_B9 (VBUS_A), J4.B4_A9 (VBUS_B), U1.22 (5V), U1.23 (5V), U1.24 (5V)
G9: SW2.b, U1.10 (G09)
G10: SW2.2 (DTA), U1.11 (G10)
G11: SW2.5 (DTA), U1.12 (G11)
G12: SW1.5 (DTA), U1.13 (G12)
G13: SW1.2 (DTA), U1.14 (G13)
G14: SW1.b, U1.15 (G14)
GND: CN1.2, J3.2, J4.A1_B12 (GND_A), J4.B1_A12 (GND_B), R1.2, R2.2, R3.2, R10.2, R11.2, SW1.1 (B), SW1.6 (B), SW2.1 (B), SW2.6 (B), U1.7 (GND), U1.20 (GND), U1.21 (GND), U1.32 (GND)
unnamed: D1.1 (K), R3.1
unnamed: J1.1, U1.40 (G46)
unnamed: J1.2, U1.39 (G45)
unnamed: J1.3, U1.38 (G42)
unnamed: J1.4, U1.37 (G41)
unnamed: J1.5, U1.36 (G15)
unnamed: J1.6, U1.35 (G16)
unnamed: J1.7, U1.34 (G17)
unnamed: J1.8, U1.33 (G18)
unnamed: J1.9, U1.31 (G21)
unnamed: J1.10, U1.30 (G40)
unnamed: J1.11, U1.29 (G39)
unnamed: J1.12, U1.28 (G38)
unnamed: J1.13, U1.27 (G47)
unnamed: J1.14, U1.26 (G48)
unnamed: J2.1, U1.1 (G01)
unnamed: J2.2, U1.2 (G02)
unnamed: J2.3, U1.3 (G03)
unnamed: J2.4, U1.4 (G04)
unnamed: J2.5, U1.5 (G05)
unnamed: J2.6, U1.6 (G06)
unnamed: J2.7, U1.8 (G07)
unnamed: J2.8, U1.9 (G08)
unnamed: J4.A5 (CC1), R11.1
unnamed: J4.B5 (CC2), R10.1
unnamed: R1.1, SW1.d
unnamed: R2.1, SW2.d

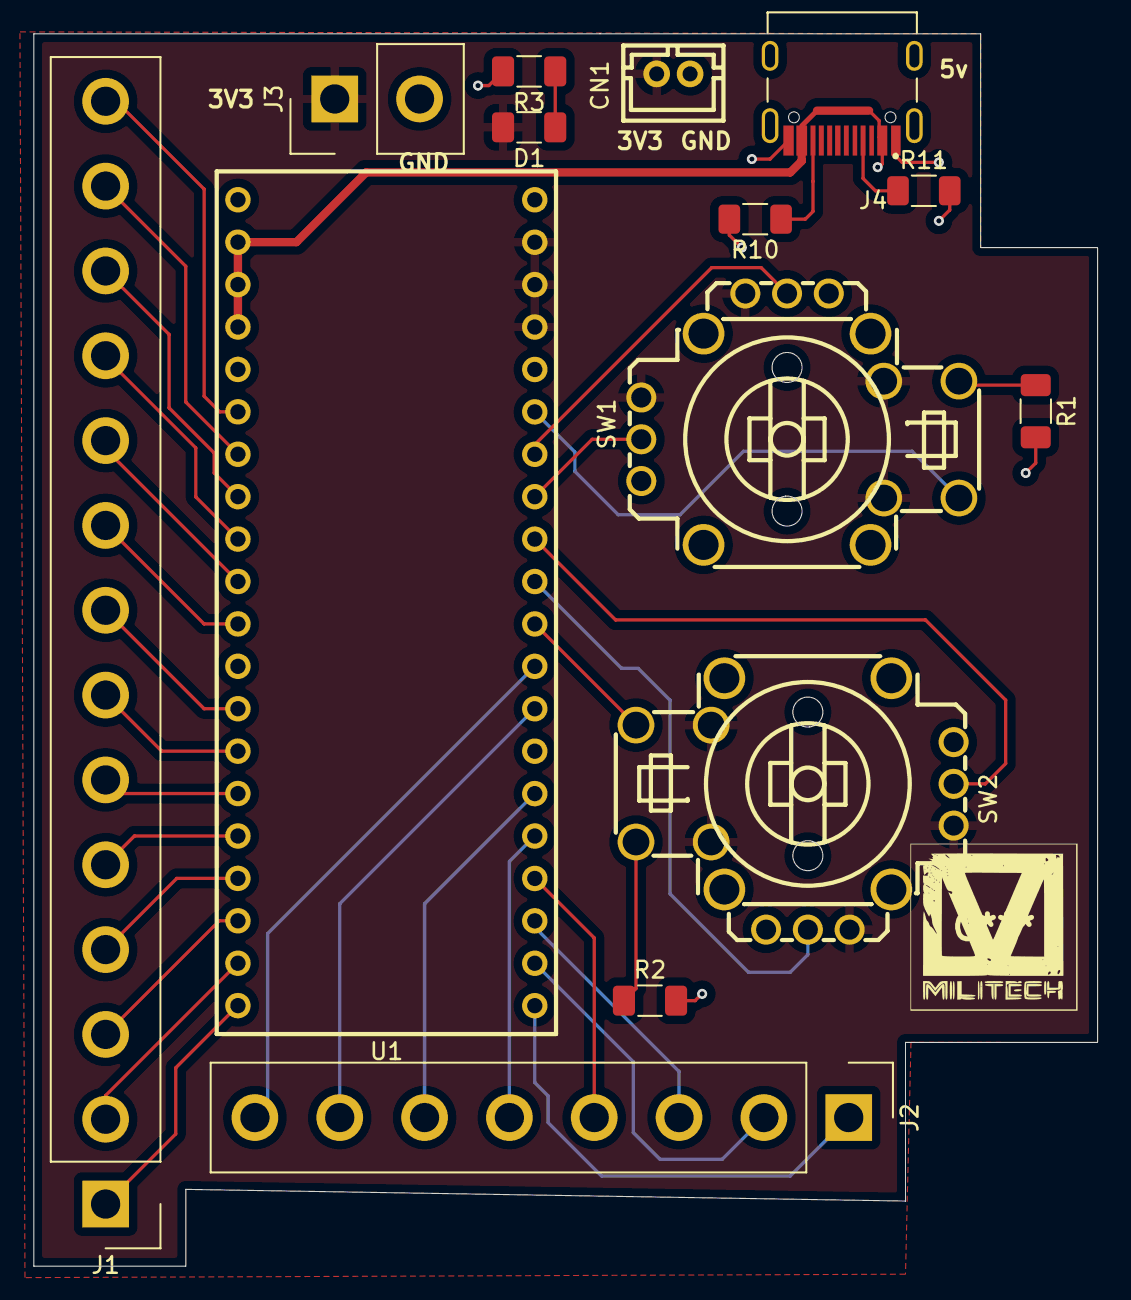
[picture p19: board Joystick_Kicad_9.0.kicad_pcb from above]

Board: 2 copper layers, 63.7 x 73.8 mm, 14 parts (0 on the bottom side), 36 nets.

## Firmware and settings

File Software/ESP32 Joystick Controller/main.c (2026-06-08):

#include <stdio.h>
#include <math.h>
#include <stdbool.h>
#include <stdint.h>

#include "freertos/FreeRTOS.h"
#include "freertos/task.h"

#include "driver/gpio.h"
#include "esp_timer.h"
#include "esp_log.h"
#include "esp_err.h"
#include "esp_adc/adc_oneshot.h"
#include "driver/i2c_master.h"
#include "esp_err.h"

//—-----I2C_Constants—---

#define I2C_SCL_GPIO 47
#define I2C_SDA_GPIO 48
#define I2C_FREQ_HZ   100000

#define C1_ADDR 0x58
#define C2_ADDR 0x59
#define C3_ADDR 0x5A
#define C4_ADDR 0x5B

static i2c_master_bus_handle_t bus_handle;
static i2c_master_dev_handle_t c1_handle;
static i2c_master_dev_handle_t c2_handle;
static i2c_master_dev_handle_t c3_handle;
static i2c_master_dev_handle_t c4_handle;

// -------------------- Pins --------------------

#define SDA_PIN   GPIO_NUM_48
#define SCL_PIN   GPIO_NUM_47
#define BUTTON1   GPIO_NUM_14
#define BUTTON2   GPIO_NUM_9   // currently unused, kept for later

// -------------------- ADC_channels --------------------

#define JOY_X_CHANNEL  ADC_CHANNEL_0
#define JOY_Y_CHANNEL  ADC_CHANNEL_1

//—------I2C Setup
static void i2c_init_four_devices(void)
{
    i2c_master_bus_config_t bus_cfg = {
        .clk_source = I2C_CLK_SRC_DEFAULT,
        .i2c_port = I2C_NUM_0,
        .scl_io_num = I2C_SCL_GPIO,
        .sda_io_num = I2C_SDA_GPIO,
        .glitch_ignore_cnt = 7,
        .flags.enable_internal_pullup = false,
    };

  ESP_ERROR_CHECK(i2c_new_master_bus(&bus_cfg, &bus_handle));

    i2c_device_config_t dev_cfg = {
        .dev_addr_length = I2C_ADDR_BIT_LEN_7,
        .scl_speed_hz = I2C_FREQ_HZ,
        .scl_wait_us = 0,
    };

    dev_cfg.device_address = C1_ADDR;
    ESP_ERROR_CHECK(i2c_master_bus_add_device(bus_handle, &dev_cfg, &c1_handle));

    dev_cfg.device_address = C2_ADDR;
    ESP_ERROR_CHECK(i2c_master_bus_add_device(bus_handle, &dev_cfg, &c2_handle));

    dev_cfg.device_address = C3_ADDR;
    ESP_ERROR_CHECK(i2c_master_bus_add_device(bus_handle, &dev_cfg, &c3_handle));

    dev_cfg.device_address = C4_ADDR;
    ESP_ERROR_CHECK(i2c_master_bus_add_device(bus_handle, &dev_cfg, &c4_handle));
}


// -------------------- Motion / IK --------------------
static float pos[3]   = {0.2f, 0.2f, 0.2f};   // x, y, z
static float joint[3]  = {0.0f, 0.0f, 0.0f};   // base yaw, shoulder, elbow/wrist placeholder
static float elbow     = 0.0f;
static float epsilon   = 0.0f;                // wrist rotation target

static float L1 = 0.50f;  // arm link 1 length
static float L2 = 0.40f;  // arm link 2 length
static bool elbowUp = true;

static const int minCap = 100;               // joystick deadzone half-width
static const float maxReach = 0.50f + 0.40f; // L1 + L2
static const float POSITION_EPS = 1e-4f;

static const float MAX_LINEAR_SPEED = 0.25f;  // m/s
static const float MAX_Z_SPEED      = 0.10f;   // m/s
static const float MAX_WRIST_SPEED  = 0.78539816339f; // rad/s = pi/4

static const char *TAG = "JOY";

static adc_oneshot_unit_handle_t adc1_handle;
static int64_t last_time_us = 0;

// -------------------- helpers --------------------
static inline float clampf_local(float v, float lo, float hi)
{
    if (v < lo) return lo;
    if (v > hi) return hi;
    return v;
}

static float joystickDirectionConvert(int raw)
{
    const int center = 2048;
    int delta = raw - center;

    if (abs(delta) <= minCap) {
        return 0.0f;
    }

    float out = (float)delta / 2048.0f;

    // Clamp to [-1, 1]
    out = clampf_local(out, -1.0f, 1.0f);
    return out;
}

static void limitRadius(void)
{
    float radius = sqrtf(pos[0] * pos[0] + pos[1] * pos[1] + pos[2] * pos[2]);

    if (radius > maxReach && radius > 0.0f) {
        float scale = maxReach / radius;
        pos[0] *= scale;
        pos[1] *= scale;
        pos[2] *= scale;
    }
}

static void inverseKinematics(void)
{
    // Treat pos[0], pos[1] as base plane x/y, pos[2] as vertical z.
    float x = pos[0];
    float y = pos[1];
    float z = pos[2];

    float r_xy = sqrtf(x * x + y * y);
    float d = sqrtf(r_xy * r_xy + z * z);

    if (d < POSITION_EPS) {
        d = POSITION_EPS;
    }

    float cos_elbow = (L1 * L1 + L2 * L2 - d * d) / (2.0f * L1 * L2);
    cos_elbow = clampf_local(cos_elbow, -1.0f, 1.0f);
    elbow = acosf(cos_elbow);

    float cos_shoulder = (L1 * L1 + d * d - L2 * L2) / (2.0f * L1 * d);
    cos_shoulder = clampf_local(cos_shoulder, -1.0f, 1.0f);
    float shoulder_offset = acosf(cos_shoulder);

    float base_yaw = atan2f(y, x);
    float elevation = atan2f(z, r_xy);

    joint[0] = base_yaw;
    joint[1] = elbowUp ? (elevation + shoulder_offset) : (elevation - shoulder_offset);
    joint[2] = epsilon;
}



static int read_joystick_axis(adc_channel_t channel)
{
    int raw = 0;
    ESP_ERROR_CHECK(adc_oneshot_read(adc1_handle, channel, &raw));
    return raw;
}

static void parseJoystick(float dt)
{
    int xRaw = read_joystick_axis(JOY_X_CHANNEL);
    int yRaw = read_joystick_axis(JOY_Y_CHANNEL);

    float xAxis = joystickDirectionConvert(xRaw);
    float yAxis = joystickDirectionConvert(yRaw);

    // Button pressed = active-low with pull-up enabled.
    bool pressed = (gpio_get_level(BUTTON1) == 0);

    if (pressed) {
        // While pressed: use stick for z + wrist
        pos[2] += yAxis * MAX_Z_SPEED * dt;
        epsilon += xAxis * MAX_WRIST_SPEED * dt;
    } else {
        // Normal mode: move x/y
        pos[0] += xAxis * MAX_LINEAR_SPEED * dt;
        pos[1] += yAxis * MAX_LINEAR_SPEED * dt;
    }

    limitRadius();
    inverseKinematics();
}

static void init_gpio(void)
{
    gpio_config_t io_conf = {
        .pin_bit_mask = (1ULL << BUTTON1),
        .mode = GPIO_MODE_INPUT,
        .pull_up_en = GPIO_PULLUP_ENABLE,
        .pull_down_en = GPIO_PULLDOWN_DISABLE,
        .intr_type = GPIO_INTR_DISABLE
    };
    ESP_ERROR_CHECK(gpio_config(&io_conf));
}

static void init_adc(void)
{
    adc_oneshot_unit_init_cfg_t unit_cfg = {
        .unit_id = ADC_UNIT_1,
        .ulp_mode = ADC_ULP_MODE_DISABLE,
    };
    ESP_ERROR_CHECK(adc_oneshot_new_unit(&unit_cfg, &adc1_handle));

    adc_oneshot_chan_cfg_t chan_cfg = {
        .atten = ADC_ATTEN_DB_12,
        .bitwidth = ADC_BITWIDTH_DEFAULT,
    };

    ESP_ERROR_CHECK(adc_oneshot_config_channel(adc1_handle, JOY_X_CHANNEL, &chan_cfg));
    ESP_ERROR_CHECK(adc_oneshot_config_channel(adc1_handle, JOY_Y_CHANNEL, &chan_cfg));
}

static void joystick_task(void *arg)
{
    last_time_us = esp_timer_get_time();

    while (1) {
        int64_t now_us = esp_timer_get_time();
        float dt = (now_us - last_time_us) / 1000000.0f;
        last_time_us = now_us;

        if (dt < 0.0f) dt = 0.0f;
        if (dt > 0.1f) dt = 0.1f;

        // 1. Read joysticks and calculate Inverse Kinematics
        parseJoystick(dt);

        // 2. Transmit the freshly computed angles to your 4 motor controllers
        send_to_all_four();

        // 3. Log the status updates
        ESP_LOGI(TAG,
                 "pos=(%.3f, %.3f, %.3f)  joint=(%.3f, %.3f, %.3f)  elbow=%.3f",
                 pos[0], pos[1], pos[2],
                 joint[0], joint[1], joint[2],
                 elbow);

        // 4. Yield CPU control for 10ms (Allows background tasks to breathe)
        vTaskDelay(pdMS_TO_TICKS(10));
    }
}
void send_motor_command(
    i2c_master_dev_handle_t dev,
    float angle_rad,
    uint8_t speed)
{
    uint8_t tx_buf[4];

    float angle_deg = angle_rad * 180.0f / M_PI;

    uint8_t direction;

    if (angle_deg >= 0.0f)
    {
        direction = 1;
    }
    else
    {
        direction = 0;
        angle_deg = -angle_deg;
    }

    // clamp to representable range
    if (angle_deg > 359.99f)
    {
        angle_deg = 359.99f;
    }

    uint16_t angle_encoded = (uint16_t)(angle_deg * 100.0f);

    tx_buf[0] = (angle_encoded >> 8) & 0xFF;
    tx_buf[1] = angle_encoded & 0xFF;
    tx_buf[2] = direction;
    tx_buf[3] = speed;

    ESP_ERROR_CHECK(
        i2c_master_transmit(
            dev,
            tx_buf,
            sizeof(tx_buf),
            pdMS_TO_TICKS(100)
        )
    );
}




void app_main(void) { // Initialize Hardware Peripherals

 init_gpio();
 init_adc(); 
i2c_init_four_devices(); // Create the infinite cyclic control task 
xTaskCreate(joystick_task, "joystick_task", 4096, NULL, 5, NULL); 

// app_main can safely finish or delete itself; // FreeRTOS keeps the spawned task alive. vTaskDelete(NULL); }

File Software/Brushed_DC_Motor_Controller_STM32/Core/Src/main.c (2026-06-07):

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
/* Includes ------------------------------------------------------------------*/
#include "main.h"

/* USER CODE BEGIN PTD */
void parseI2C();
void fail();
float Proportional(int err);
float Derivative(int err);
float Integral(int err);
void HAL_TIM_PeriodElapsedCallback(TIM_HandleTypeDef* htim);
void PID_Response(float output);
void turnReverse(float duty);
void turnForward(float duty);

/* USER CODE END PTD */

/* USER CODE BEGIN PD */
extern I2C_HandleTypeDef hi2c1;
float int absPosition=0;

int var = 0;
int rot = 0;
int speed = 0;
int direction = 1; //left is 0, right is 1
int currentPosition = 0;
int targetPosition= 0;
float previousTarget = 0;
int error = 0;

int accum = 0; //Accumulated integral. Will reset when desired position changes
int tempProp = 0; //the previous error, used to calculate derivative

float Kd= 1; // derivative coefficient
float Kp= 1; // proportional coefficient
float Ki= 1; //integral coefficient

float sum = 0; //sum of all three PID parts
uint8_t RX_Buffer [4]; //buffer for [2 bytes for angle number (0 to 359.9945 degrees)], 1 byte number (0 for left or 1 for right), [1 byte 0-255 (speed)

/* USER CODE END PD */


void SystemClock_Config(void);
/**
  * @brief  The application entry point.
  * @retval int
  */
int main(void)
{

  /* MCU Configuration--------------------------------------------------------*/

  /* Reset of all peripherals, Initializes the Flash interface and the Systick. */
  HAL_Init();

  /* Configure the system clock */
  SystemClock_Config();

  /* Initialize all configured peripherals */
  /* Infinite loop */
  /* USER CODE BEGIN WHILE */
  while (1)
  {
	  parseI2C();
	  if (targetPosition != previousTarget){
		  accum = 0;
		  previousTarget = targetPosition;
	  }

    /* USER CODE END WHILE */

    /* USER CODE BEGIN 3 */
  }
  /* USER CODE END 3 */
}

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
/* USER CODE BEGIN 4 */

void PID_Response(float output){

if (output < 0 ){
turnReverse(-output);
}

else {
turnForward(output);
 }
}

void turnForward(float duty){
TIM3 -> CCR2 = duty; //INA1
TIM3 -> CCR1 =0 ; //INA2
}

void turnReverse(float duty){
TIM3 -> CCR2 = 0; //INA1
TIM3 -> CCR1 = duty; //INA2
}


void HAL_TIM_PeriodElapsedCallback(TIM_HandleTypeDef* htim){
error = targetPosition - currentPosition; //measured in angles
if (error > 180){
error = error - 360;
}
if (error < -180){
error = error + 360;
}
absPosition += error;
if (absPosition >= 180){
absPosition = 180;
}
if (absPosition <= -180){
absPosition = -180;
}

sum = Proportional(error) + Integral(error) + Derivative(error);
if (sum > TIM3->ARR) {
sum = TIM3->ARR;
}
if (sum < -1 * TIM3->ARR) {
sum = -1* TIM3->ARR; //clamping PID Response
}
PID_Response(sum);
}
//SUM RANGES FROM -1279 to 1279



void parseI2C(){
HAL_StatusTypeDef Ret;
Ret = HAL_I2C_Slave_Receive(&hi2c1 ,RX_Buffer, 4,1000);
if (Ret != HAL_OK){
fail();
}
else{
HAL_I2C_Slave_Transmit(&hi2c1,RX_Buffer, 4, 1000);
}

targetPosition = ((RX_Buffer[0] << 8) | RX_Buffer[1]) * 360 / 65535;

direction = RX_Buffer[2];

speed = RX_Buffer[3];}
void fail(){
printf("Oopsies! Look like there’s a problem =<");

}

float Proportional(int err){

return Kp * err;
}

float Integral(int err){
accum += err;
if (accum >= 1000000){
	  accum = 1000000;
	  }
if (accum <= -1000000){
	  accum = -1000000;
	  }
return (Ki * accum);

}

float Derivative(int err){
int temp = tempProp;
tempProp = err; //also make sure this updates the global variable tempProp
return ((tempProp - temp)/(0.01) * Kd);
}

//Okay, now Var should hold the values transmitted by I2C. Example, [0x00][0xB4][0x01][0x80]

/* USER CODE END 4 */
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


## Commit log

2026-06-07 Added BOM
    [BOM Final.csv]
2026-06-07 Added STM32 code for brushed DC Motor
2026-06-08 added esp32 IDF firmware
2026-06-08 updated BOM #1
2026-06-08 updated BOM #2

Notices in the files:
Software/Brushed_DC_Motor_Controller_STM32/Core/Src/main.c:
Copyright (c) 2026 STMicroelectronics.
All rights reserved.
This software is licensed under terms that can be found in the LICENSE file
